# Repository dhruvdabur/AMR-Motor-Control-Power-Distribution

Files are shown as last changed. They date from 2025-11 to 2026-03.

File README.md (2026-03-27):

# AMR-Motor-Control-Power-Distribution


Certainly — here it is in a clear pointer-based format:

## AMR-Motor-Control-Power-Distribution

* A custom-designed PCB that acts as the **central power distribution** and **low-level control unit** of the autonomous mobile robot. 
* Distributes power from the **24V battery** to the robot’s major subsystems, including:

  * **Base motors**
  * **Robotic arm**
  * **Onboard Jetson compute module**
  * **Supporting electronics and sensors** 

## Power Regulation

* Includes **buck converters** to step down the input voltage to the required levels for different subsystems. 
* Provides **stable and regulated power delivery** to components with different voltage requirements.
* Improves overall system efficiency through localized voltage regulation.

## Control Architecture

* Integrates **two electrically isolated STM32F411 microcontrollers**. 
* The microcontrollers are responsible for:

  * **Motor control**
  * **Encoder data handling**
  * **IMU data handling**
  * **Communication with the Jetson compute module** 
* Electrical isolation between control and power sections helps:

  * Reduce electrical noise
  * Improve system reliability
  * Protect sensitive electronics from faults in high-current sections

## Protection and Reliability Features

* Designed with a strong focus on **electrical protection** and **robust operation**. 
* Protection features include:

  * **Galvanic isolation**
  * **Isolated DC-DC converters**
  * **Polyfuses**
  * **TVS diodes** 
* These features help protect the system against:

  * Overcurrent conditions
  * Voltage spikes
  * Electrical noise and transients
* Includes an **emergency kill switch** with **fuse protection** in the main power path for safe and immediate shutdown. 

## System Design Advantages

* Separates **power electronics**, **sensing**, and **computing** into distinct electrical domains. 
* Improves:

  * **Serviceability**
  * **Fault isolation**
  * **Debugging efficiency**
  * **Long-term system reliability**
* Plays a key role in ensuring stable operation of the robot in demanding autonomous applications.

I can also merge this with your **dual-STM isolation scheme** section so the whole README reads in one consistent pointer-based style.

## The Two Brains 



Got it. For a schematic description, pointer-style is better.

You can write it like this:

## Isolation and Communication Architecture

* The board uses **two STM32 microcontrollers** arranged in **separate electrical domains**. 
* The two controllers communicate through **optocouplers**, providing electrical isolation between the domains.
* Communication across the isolation barrier consists of:

  * **1 clock synchronization line**
  * **2 UART lines**
* This arrangement allows reliable data exchange while reducing the effect of electrical noise and preventing fault propagation between subsystems.

## Powering Scheme

* One STM32 is powered using an **isolated DC-DC converter**.
* The other STM32 is powered directly from the **raw power rail**.
* This split power architecture helps isolate sensitive control and sensing electronics from noisy power sections.

## Functional Division Between the Two STM32s

### STM32-1

* Receives **encoder data**
* Sends encoder feedback to the **Jetson**
* Receives **motor actuation commands** from the Jetson through **USB CDC**
* Acts as the main communication bridge to the Jetson

### STM32-2

* Acquires **IMU data**
* Sends IMU data to **STM32-1**

## Data Flow

* **Jetson → STM32-1**: motor actuation commands via USB CDC
* **STM32-2 → STM32-1**: IMU data
* **STM32-1 → Jetson**: encoder data and forwarded IMU data

## Design Benefits

* Clear separation of sensing and control responsibilities
* Reduced electrical interference between domains
* Improved robustness in noisy motor-control environments
* Easier debugging and modular system integration

Here is an even shorter README-style version:

## Dual-STM Isolation Scheme

* Two STM32 microcontrollers are used in separate electrical domains.
* The domains are isolated using optocouplers.
* Cross-domain communication uses **one clock synchronization line** and **two UART lines**.
* One STM32, powered through an isolated DC-DC converter, handles encoder acquisition and Jetson communication over USB CDC for motor commands.
* The second STM32, powered from the raw supply, handles IMU acquisition and sends this data to the first STM32.
* The first STM32 forwards the combined feedback data to the Jetson.



## Switch Layout

* The schematic includes three primary power switches: **Main Kill**, **Arm Kill**, and **Base Kill**.
* The **Main Kill Switch** controls overall system power.
* The **Arm Kill Switch** only disables the arm power domain.
* The **Base Kill Switch** only disables the base power domain.
* The **Jetson remains powered even when the Arm Kill Switch is turned off**, allowing computation and system monitoring to continue independently of the arm power domain.



## Fuse Layout and Protection

* The schematic includes **three main fuses on the PCB**:

  * one for the **IMU**
  * one for **each STM32 microcontroller**
* These fuses protect the low-power sensing and control sections of the board.
* In addition, **one fuse may also be added along with each kill switch**, depending on the required level of subsystem protection.
* This design provides better electrical safety and allows faults to be isolated more effectively across different power domains.




You can write it like this:

## High-Current Power Routing

* The high-current section of the PCB is laid out as a **separate and clearly defined power zone**.
* This section is designed with **wider copper paths** to support higher current flow with lower resistance.
* Special attention has been given to the **battery input terminal** to improve current-carrying capability.
* In this region, the **solder mask has been removed intentionally** so that additional solder can be added over the copper.
* Adding extra solder increases the effective conductive cross-section and helps the board handle higher current more reliably.
* This layout improves:

  * **current-carrying capacity**
  * **thermal performance**
  * **power delivery reliability** under heavy load



## Acknowledgment and Conclusion

* This project represents the combined effort of the entire electronics team and all the members who contributed to making this AMR possible.
* The development of the AMR-Motor-Control-Power-Distribution board was made possible through continuous design, testing, debugging, and integration across multiple subsystems.
* Special acknowledgment goes to all the members of the electronics system whose work on power distribution, control, sensing, protection, and system integration contributed to the successful realization of this project.
* This board serves as a key part of the robot’s electrical architecture, enabling reliable power delivery, subsystem isolation, and robust low-level control.
* With this work, the project establishes a strong foundation for stable and scalable operation of the autonomous mobile robot.

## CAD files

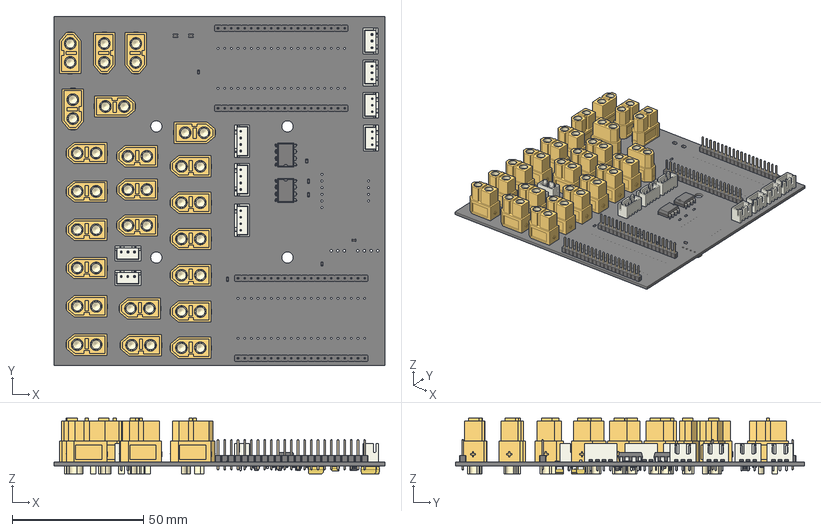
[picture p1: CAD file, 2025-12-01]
base/RCUP_BASE_PCB_2.step
126.2 x 133.1 x 21.2 mm
Fuse_0603_1608Metric x 3
AMASS_XT60-F_1x02_P7.2mm_Vertical x 23
JST_XH_B3B-XH-A_1x03_P2.50mm_Vertical x 6
R_0603_1608Metric x 14
PinHeader_1x20_P2.54mm_Vertical x 4
JST_XH_B4B-XH-A_1x04_P2.50mm_Vertical x 3
DIP-8_W7.62mm x 2
C_0603_1608Metric x 2
D_0805_2012Metric x 2
CP_EIA-6032-28_Kemet-C x 3
SOT-23-6 x 5
CP_EIA-3216-18_Kemet-A
RCUP_BASE_PCB_2_PCB

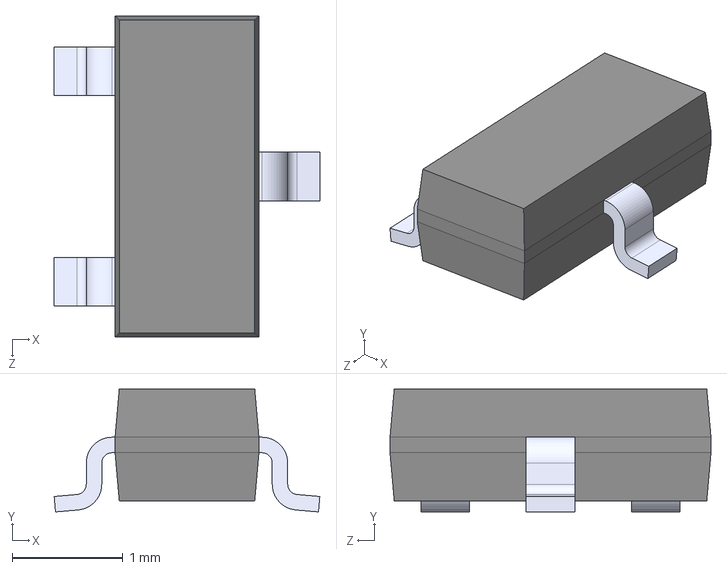
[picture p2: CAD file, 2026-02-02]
BSS138/BSS138.step
2.40 x 1.11 x 2.90 mm

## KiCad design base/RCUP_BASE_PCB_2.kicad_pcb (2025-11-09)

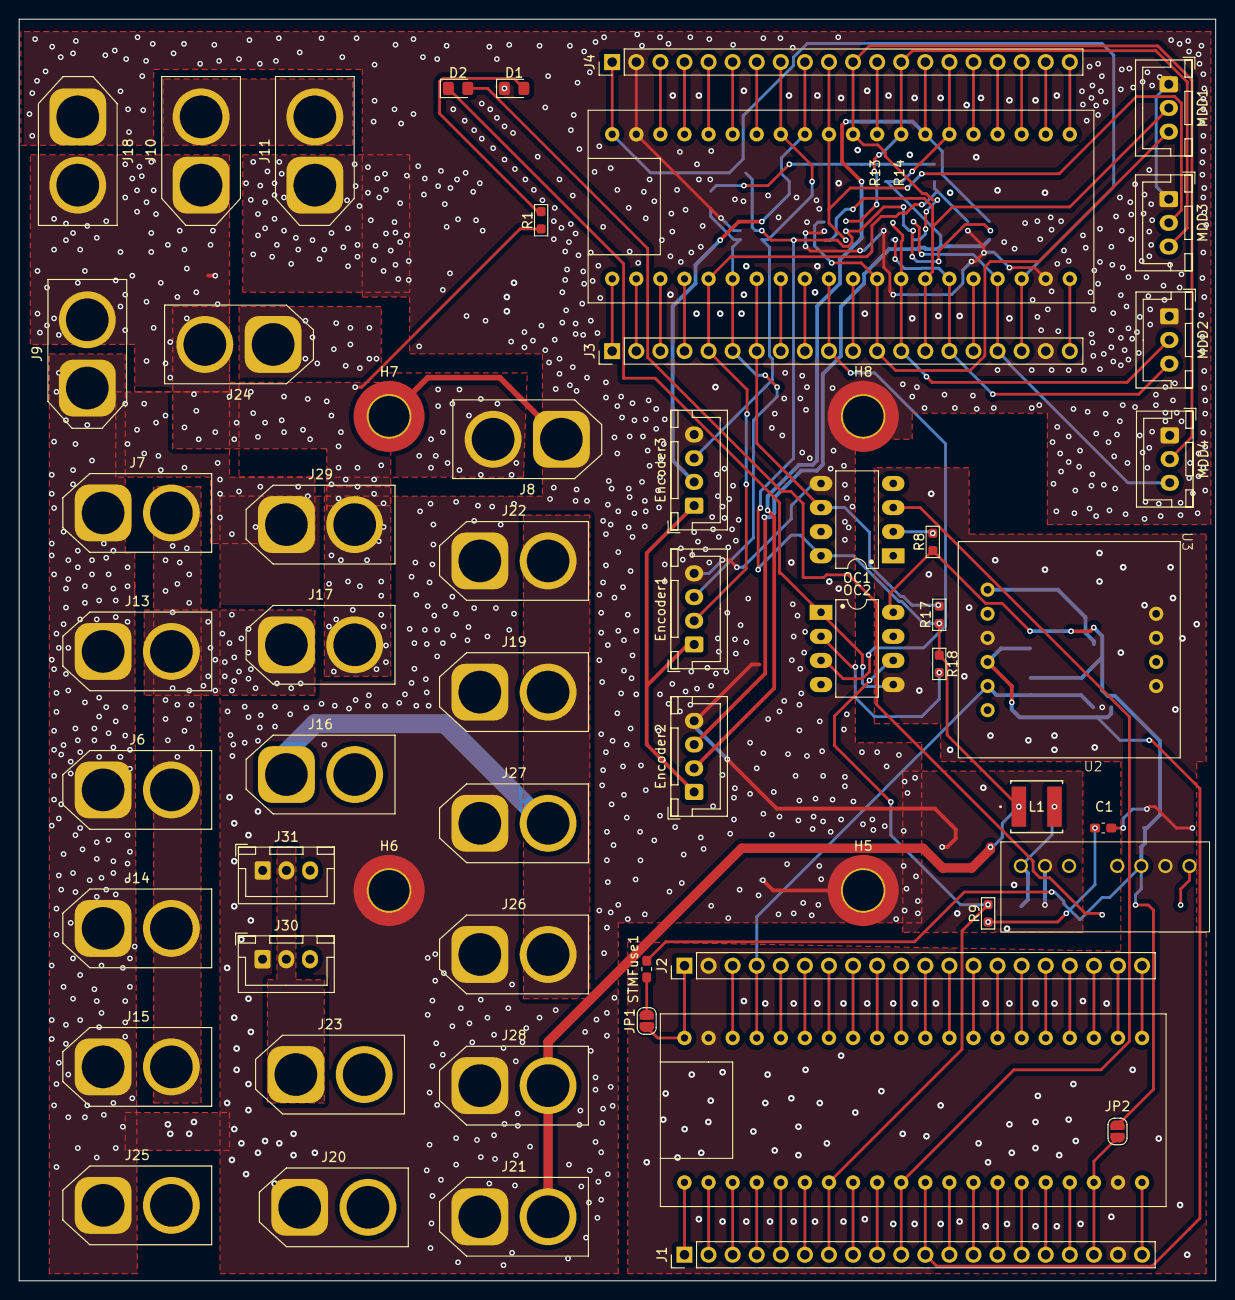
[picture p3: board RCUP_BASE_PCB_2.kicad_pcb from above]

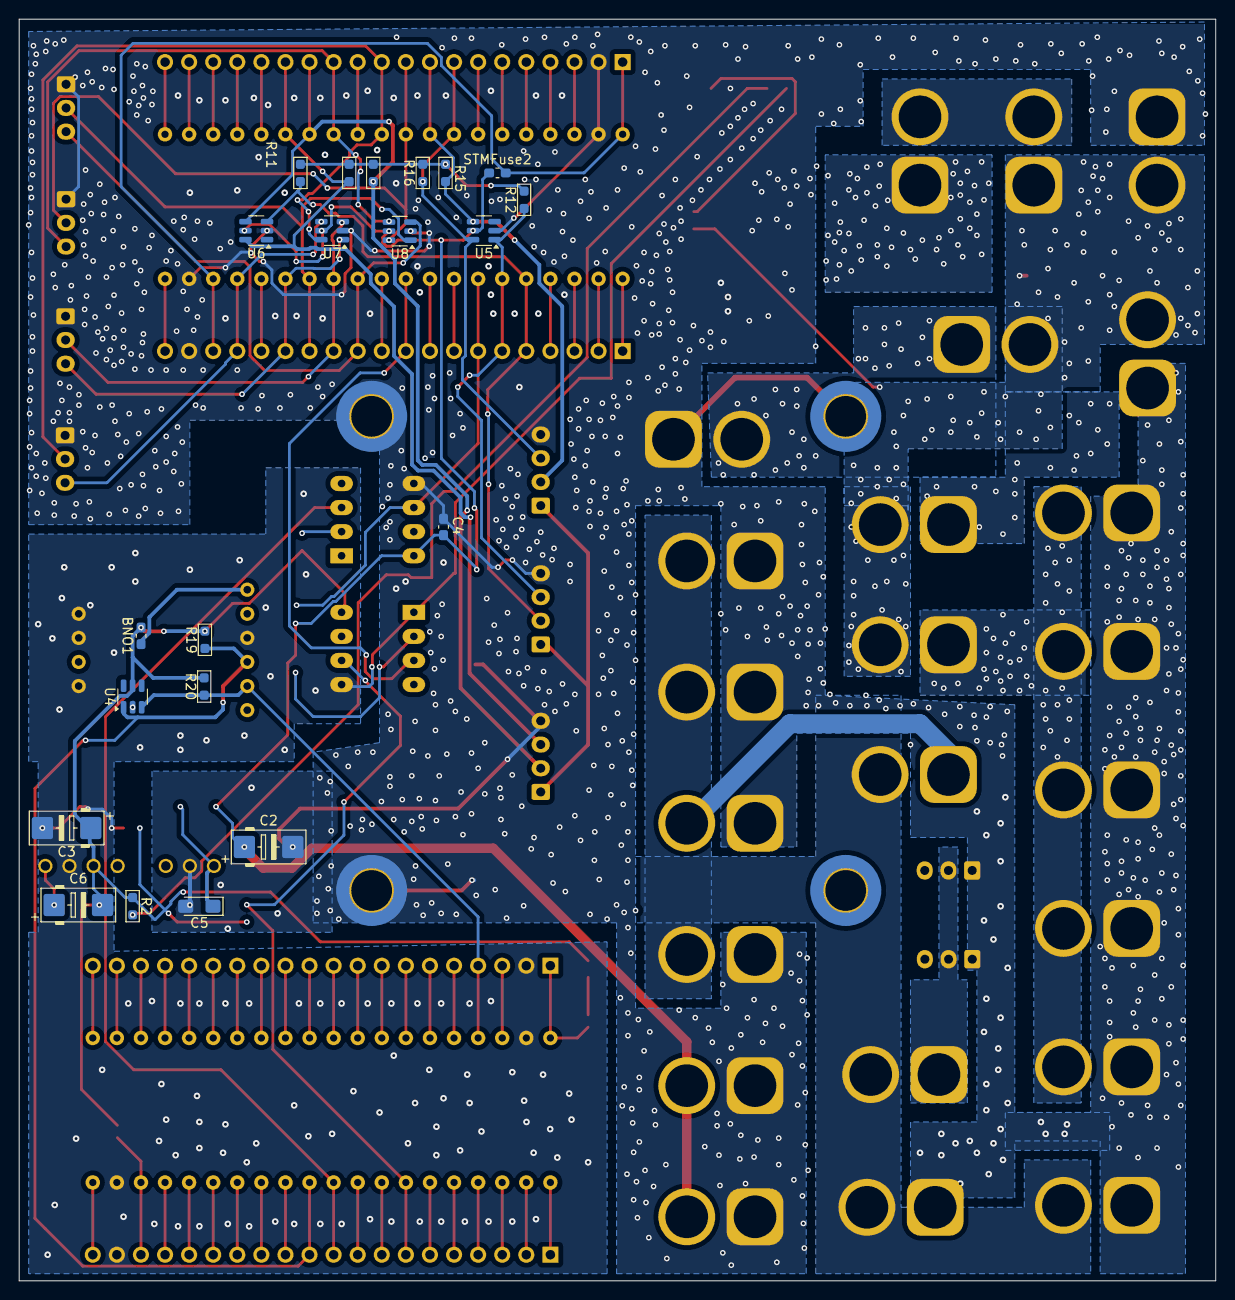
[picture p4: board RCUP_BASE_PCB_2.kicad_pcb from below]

Board: 2 copper layers, 126.2 x 133.1 mm, 79 parts (21 on the bottom side), 46 nets.

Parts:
BNO1: Polyfuse; Fuse_0603_1608Metric_Pad1.05x0.95mm_HandSolder
C1, C4: 0.1µ; C_0603_1608Metric_Pad1.08x0.95mm_HandSolder
C2, C3: 100µ; CP_EIA-6032-28_Kemet-C_Pad2.25x2.35mm_HandSolder
C5: 47µ; CP_EIA-3216-18_Kemet-A_HandSolder
C6: 10µ; CP_EIA-6032-28_Kemet-C_Pad2.25x2.35mm_HandSolder
D1, D2: LED; D_0805_2012Metric_Pad1.15x1.40mm_HandSolder
Encoder1, Encoder2, Encoder3: Conn_01x04_Pin; JST_XH_B4B-XH-A_1x04_P2.50mm_Vertical
H5, H6, H7, H8: MountingHole_Pad; MountingHole_4.3mm_M4_DIN965_Pad_TopBottom
J1, J2, J3, J4: Conn_01x20_Pin; PinHeader_1x20_P2.54mm_Vertical
J6: MOTOR 1 PWR; xt60
J7: MOTOR 3 PWR; xt60
J8: STEPPER AND BLDC POWER; xt60
J9: JETSON POWER; xt60
J10: MAIN KILL SWITCH; xt60
J11: BatteryIN; xt60
J13: MOTOR 2 PWR; xt60
J14: MOTOR 4 PWR; xt60
J15: 24V TO 5V BUCK IN; xt60
J16: BASE KILL SWITCH 12V; xt60
J17: BASE KILL SWITCH 24V; xt60
J18: 24V TO 12V BUCK IN; xt60
J19, J20, J25, J26: COOLING SYSTEM; xt60
J21: 24V TO 5V BUCK OUT; xt60
J22: 24V TO 12V BUCK OUT; xt60
J23: ARM KILL SWITCH 12V; xt60
J24: ARM KILL SWITCH; xt60
J27: EXTRA 12V PORT; xt60
J28: EXTRA 5V PORT; xt60
J29: EXTRA 24V PORT; xt60
J30, J31: Conn_01x03_Pin; JST_XH_B3B-XH-A_1x03_P2.50mm_Vertical
JP1, JP2: SolderJumper_2_Open; SolderJumper-2_P1.3mm_Open_RoundedPad1.0x1.5mm
L1: 4.7µ; IND_SWPA5040S_SNL-M
MDD1, MDD2, MDD3, MDD4: Conn_01x03_Pin; JST_XH_B3B-XH-A_1x03_P2.50mm_Vertical
MotorController1, MotorController2: STM32F411_BP; STM32F411-BP
OC1, OC2: 6N137; DIP-8_W7.62mm_LongPads
R1: 1K; R_0603_1608Metric_Pad0.98x0.95mm_HandSolder
R2: 220; R_0603_1608Metric_Pad0.98x0.95mm_HandSolder
R8, R9, R17, R18: 350; R_0603_1608Metric_Pad0.98x0.95mm_HandSolder
R11, R12, R13, R14, R15, R16: 6R8K; R_0603_1608Metric_Pad0.98x0.95mm_HandSolder
R19, R20: 4R7K; R_0603_1608Metric_Pad0.98x0.95mm_HandSolder
STMFuse1, STMFuse2: Polyfuse; Fuse_0603_1608Metric_Pad1.05x0.95mm_HandSolder
U2: WRB0505S-3WR3
U3: BNO055; 7_semi_BNO055
U4, U5, U6, U7, U8: USBLC6-4SC6; SOT-23-6

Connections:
3.3V_STM_1: J2.3, MotorController1.3 (3V3)
3.3V_STM_2: J4.3, MotorController2.3 (3V3)
5V: C2.1, C4.1, J21.P (POS), J28.P (POS), L1.1, OC1.8 (VCC), R17.1, R18.1, STMFuse2.1, U5.5 (VBUS), U6.5 (VBUS), U7.5 (VBUS), U8.5 (VBUS)
5VIn: Encoder1.1, Encoder2.1, Encoder3.1
5V_ISO: BNO1.2, C1.1, C3.1, C6.2, JP2.1 (A), OC2.8 (VCC), R2.1, R8.1, R9.1, R19.2, R20.2, STMFuse1.2, U2.5 (+vo), U4.5 (VBUS)
5V_ISO_BNO: BNO1.1, U3.1 (Vin)
5V_ISO_FUSE_OUT: JP1.2 (B), STMFuse1.1
5V_NON_ISO: R11.2, R12.2, R13.2, R14.2, R15.2, R16.2
5V_NON_ISO_IN: J3.18, J4.1, MotorController2.1 (5V), MotorController2.38 (5V), STMFuse2.2
12V: J16.P (POS), J19.P (POS), J20.P (POS), J22.P (POS), J23.P (POS), J25.P (POS), J26.P (POS)
12V_ARM: J23.N (NEG), J30.2, J31.2
12V_BASE: J16.N (NEG), J27.P (POS)
24V: J9.P (POS), J10.N (NEG), J17.P (POS), J18.P (POS), J24.P (POS), J29.P (POS), R1.1
24V_ARM: J8.P (POS), J24.N (NEG)
24V_BASE: J6.P (POS), J7.P (POS), J13.P (POS), J14.P (POS), J15.P (POS), J17.N (NEG)
24V_BATTERY: J10.P (POS), J11.P (POS)
BNO_SCL: J2.4, MotorController1.4 (PB10), R20.1, U3.5 (SCL), U4.3 (I/O2)
BNO_SDA: J1.11, MotorController1.31 (PB3), R19.1, U3.4 (SDA), U4.1 (I/O1)
ENC1A: Encoder1.2, J3.5, MotorController2.25 (PA8), R11.1, U6.3 (I/O2)
ENC1B: Encoder1.3, J3.6, MotorController2.26 (PA9), R12.1, U5.1 (I/O1)
ENC2A: Encoder2.2, J4.14, MotorController2.14 (PA1), R14.1, U6.4 (I/O3)
ENC2B: Encoder2.3, J4.15, MotorController2.15 (PA0), R13.1, U6.6 (I/O4)
ENC3A: Encoder3.2, J4.9, MotorController2.9 (PA6), R15.1, U5.4 (I/O3)
ENC3B: Encoder3.3, J4.8, MotorController2.8 (PA7), R16.1, U5.6 (I/O4)
GND: C2.2, C4.2, C5.2, D1.1 (K), Encoder1.4, Encoder2.4, Encoder3.4, H5.1, H6.1, H7.1, H8.1, J3.19, J4.2, J6.N (NEG), J7.N (NEG), J8.N (NEG), J9.N (NEG), J11.N (NEG), J13.N (NEG), J14.N (NEG), J15.N (NEG), J18.N (NEG), J19.N (NEG), J20.N (NEG), J21.N (NEG), J22.N (NEG), J25.N (NEG), J26.N (NEG), J27.N (NEG), J28.N (NEG), J29.N (NEG), J30.1, J31.1, MDD1.1, MDD2.1, MDD3.1, MDD4.1, MotorController2.2 (GND), MotorController2.39 (GND), OC1.5 (GND), U2.2 (-vin), U5.2 (GND), U6.2 (GND), U7.2 (GND), U8.2 (GND)
GND1: C1.2, C3.2, D2.1 (K), J1.19, J2.2, MotorController1.2 (GND), MotorController1.39 (GND), OC2.5 (GND), U2.6 (-vo), U3.3 (GND), U3.7 (PS0), U3.8 (PS1), U3.10 (ADD), U4.2 (GND)
M1DIR: J3.12, MDD1.3, MotorController2.32 (PB4), U8.3 (I/O2)
M1PWM: J3.14, MDD1.2, MotorController2.34 (PB6), U8.1 (I/O1)
M2DIR: J3.13, MDD2.2, MotorController2.33 (PB5), U7.3 (I/O2)
M2PWM: J3.15, MDD2.3, MotorController2.35 (PB7), U7.1 (I/O1)
M3DIR: J4.10, MDD3.2, MotorController2.10 (PA5), U8.6 (I/O4)
M3PWM: J4.13, MDD3.3, MotorController2.13 (PA2), U8.4 (I/O3)
M4DIR: J4.11, MDD4.2, MotorController2.11 (PA4), U7.6 (I/O4)
M4PWM: J3.17, MDD4.3, MotorController2.37 (PB9), U7.4 (I/O3)
unnamed: D1.2 (A), R1.2
unnamed: D2.2 (A), R2.2
unnamed: J1.18, JP2.2 (B), MotorController1.38 (5V)
unnamed: J2.1, JP1.1 (A), MotorController1.1 (5V)
unnamed: OC1.2, R8.2
unnamed: OC2.2, R18.2
unnamed: C5.1, L1.2, U2.1 (+vin)
unnamed: C6.1, U2.7 (Cs)
STM1_RX: J1.7, MotorController1.27 (PA10), OC2.6, R9.2
STM1_TX: J1.10, MotorController1.30 (PA15), OC1.3
STM2_RX: J3.7, MotorController2.27 (PA10), OC1.6, R17.2
STM2_TX: J3.10, MotorController2.30 (PA15), OC2.3

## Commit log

2025-10-24 fixed labels
    [base.kicad_pcb, base.kicad_sch, isolation.kicad_sch]
2025-10-28 suggested corrections made
    [base.kicad_pcb, base.kicad_sch, isolation.kicad_sch]
2025-10-28 added 0603 footprint
    [base.kicad_sch, isolation.kicad_sch]
2025-10-29 made a few changes in schematic
    [base.kicad_sch, isolation.kicad_sch]
2025-10-31 new schematic
    [RCUP_BASE_PCB_2.kicad_pcb, RCUP_BASE_PCB_2.kicad_sch, base.kicad_pcb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]
2025-10-31 changes to schematic
    [untitled.kicad_sch]
2025-10-31 changed the whole schematic and organised it
    [RCUP_BASE_PCB_2.kicad_sch, untitled.kicad_sch]
2025-11-01 components placed\
    [RCUP_BASE_PCB_2.kicad_pcb, RCUP_BASE_PCB_2.kicad_sch, untitled.kicad_sch]
2025-11-01 made the suggested changes
    [RCUP_BASE_PCB_2.kicad_sch, untitled.kicad_sch]
2025-11-03 50% routing done
    [RCUP_BASE_PCB_2.kicad_pcb, RCUP_BASE_PCB_2.kicad_sch, untitled.kicad_sch]
2025-11-04 1st iteration complete
    [RCUP_BASE_PCB_2.kicad_pcb, RCUP_BASE_PCB_2.kicad_sch, untitled.kicad_sch]
2025-11-05 2nd iteration 50% done
    [RCUP_BASE_PCB_2.kicad_pcb, RCUP_BASE_PCB_2.kicad_sch, untitled.kicad_sch]
2025-11-07 2nd iteration done
    [RCUP_BASE_PCB_2-B_Cu.gbr, RCUP_BASE_PCB_2-B_Mask.gbr, RCUP_BASE_PCB_2-B_Paste.gbr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]
2025-11-08 2nd iteration fixed
    [RCUP_BASE_PCB_2.kicad_pcb, RCUP_BASE_PCB_2.kicad_sch, untitled.kicad_sch]
2025-11-08 2nd iterations error fixed
    [RCUP_BASE_PCB_2-B_Cu.gbr, RCUP_BASE_PCB_2-B_Mask.gbr, RCUP_BASE_PCB_2-B_Paste.gbr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]
2025-11-09 fixed dfm errors some still left
    [RCUP_BASE_PCB_2-B_Cu.gbr, RCUP_BASE_PCB_2-B_Mask.gbr, RCUP_BASE_PCB_2-B_Paste.gbr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]
2025-11-09 fixed some capacitors
    [RCUP_BASE_PCB_2.kicad_pcb, RCUP_BASE_PCB_2.kicad_sch]
2025-12-01 Changes made, snapabble pdb added
    [RCUP_BASE_PCB_2.step]
2025-12-03 stm flipped
    [RCUP_BASE_PCB_2-B_Cu.gbr, RCUP_BASE_PCB_2-B_Mask.gbr, RCUP_BASE_PCB_2-B_Paste.gbr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]
2025-12-04 everything done
    [RCUP_BASE_PCB_2-B_Cu.gbr, RCUP_BASE_PCB_2-B_Mask.gbr, RCUP_BASE_PCB_2-B_Paste.gbr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]
2026-01-13 fixed all the previous issues added mpu footprint
    [RCUP_BASE_PCB_2.kicad_sch, untitled.kicad_sch]
2026-01-20 mpu addes made the traces thicker
2026-02-01 routing and stm orientation fixed
    [RCUP_BASE_PCB_2.kicad_sch]
2026-02-02 level shifter added
    [BSS138.step, RCUP_BASE_PCB_2.kicad_sch]
2026-02-05 changes made
    [RCUP_BASE_PCB_2.kicad_sch]
2026-02-12 final iteration ready
    [RCUP_BASE_PCB_2-B_Cu.gbr, RCUP_BASE_PCB_2-B_Mask.gbr, RCUP_BASE_PCB_2-B_Silkscreen.gbr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]
2026-03-27 Update README with AMR-Motor-Control-Power-Distribution details
    Added detailed description of the AMR-Motor-Control-Power-Distribution board, including its functions, components, and design considerations.
